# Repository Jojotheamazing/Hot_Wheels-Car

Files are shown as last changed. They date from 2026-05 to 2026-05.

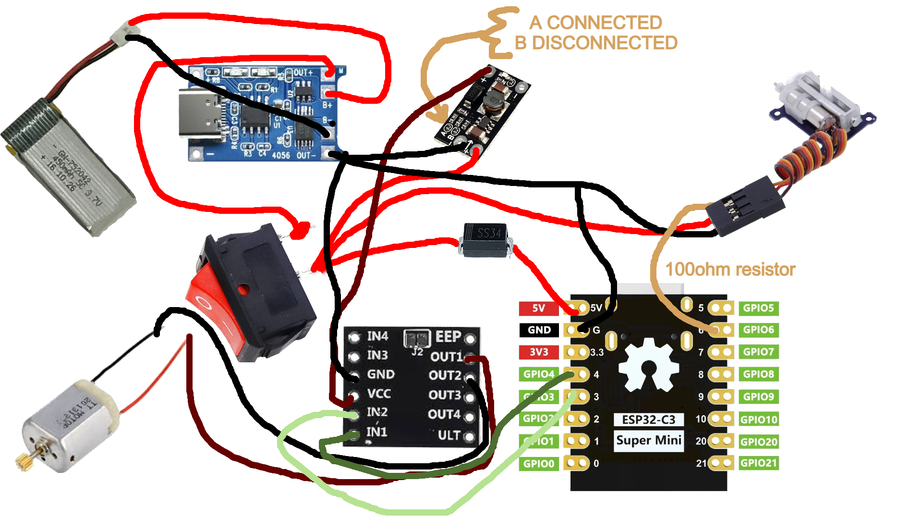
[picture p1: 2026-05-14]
Digramm.png

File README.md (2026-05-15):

# Hot_Wheels-Car

I am turning a Hot Wheels car into a fully functional RC car controlled by my phone.

So the goal is to get one of my Hot Wheels cars to be functional by adding motors, servos, and everything needed.

## The Plan

- Find the tiniest components I own since the biggest challenge will be space management.
- Design and 3D print a frame that has a steering system and holds all the components in place.
- Solder everything together and test if it goes boom or not.
- Lastly, build a website from which you can control it so there is no need to carry any controller.

## Features

- Front and backward motion through the DRV8833 motor driver.
- 45 degrees steering in each direction for better control and maybe drifting... achieved by using a 1.5 g linear servo.
- The "mind" will be an ESP32-C3 since it has Wi-Fi functions, is small, and powerful. That way control via Wi-Fi becomes possible.
- The website will be pretty basic since I can't get a specific function to work (fetch accelerometer data from phone for steering), so either 2 sliders or a joystick.
- Will include settings like:
  - Servo centre offset and limits
  - Motor limits
  - Expo throttle for smoother acceleration
  - A save button which will save the settings on the ESP32 so there isn't a need to change them every time

## Components

| Component | Purpose | Link |
|---|---|---|
| ESP32-C3 | Main controller with Wi-Fi | [AliExpress](https://www.aliexpress.com/item/1005006109082351.html) |
| DRV8833 Motor Driver | Controls the DC motor | [AliExpress]( https://www.aliexpress.com/item/1005009044264044.html) |
| 1.5 g Linear Servo | Steering system | [AliExpress](https://www.aliexpress.com/item/1005007187617708.html) |
| Coreless DC Motor | The mottion | [AliExpress](https://www.aliexpress.com/item/1005008964639480.html) |
| 601633 LiPo Battery | LiPo battery | [AliExpress](https://www.aliexpress.com/item/1005008218024646.html) |
| TP4056 Charging Module  | Battery charger | [AliExpress](https://www.aliexpress.com/item/1005005982385924.html) |
| SS12D00 3Pin Toggle Switch 1P2T 2 Position  | Power Switch | [AliExpress](https://www.aliexpress.com/item/1005005982385924.html) |
| Mini DC-DC Boost Module | Power for motor | [AliExpress](https://www.aliexpress.com/item/1005007992769446.html) |
| 1.2mm Nails | For steering wheels | Anywhere |
---
You can see and edit the 3d model in onShape: https://cad.onshape.com/documents/f10e87d5d1a2dad3236470ab/w/f1481a050fec03bc3c35e125/e/4facaef65102b49a36f9e8eb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

## Wiring

Here is an image showing all the connections but here are some notes too:
- On the boost converter you need to unsolder the b pad and only leave A soldered to set it to 9 volts
- All the Black wires are ground and it doesnt matter in which ground you connect it.
- The bright red wire is the battery power while the dark red is 9 volts so becareful not to mix it up and burn anything.
- The in1 and in2 doesnt matter if you reverse it same with out1 and out2 you might just need to reverse the diraction in the code.
  
Schematic

I should also credit an amazing YouTuber which I got inspiration for this project idea: @MaxImagination

Go check his other projects: https://www.youtube.com/@MaxImagination

Feel free to download everything and modify it however you like!

I really want to see your modifications or improvement tips, so contact me anytime!!

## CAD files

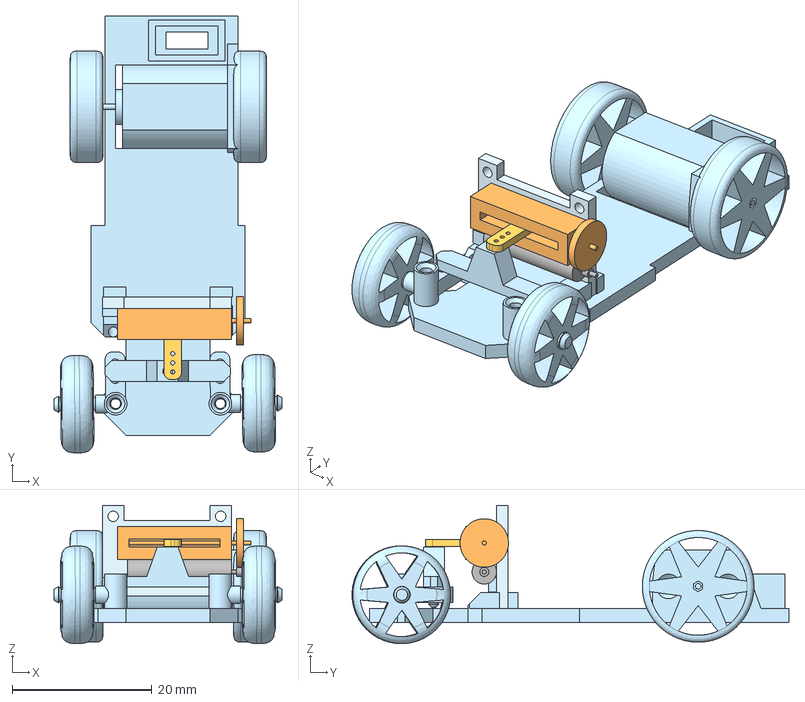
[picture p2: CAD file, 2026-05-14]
Assembly 1 Copy 1.step
32.6 x 62.6 x 19.8 mm

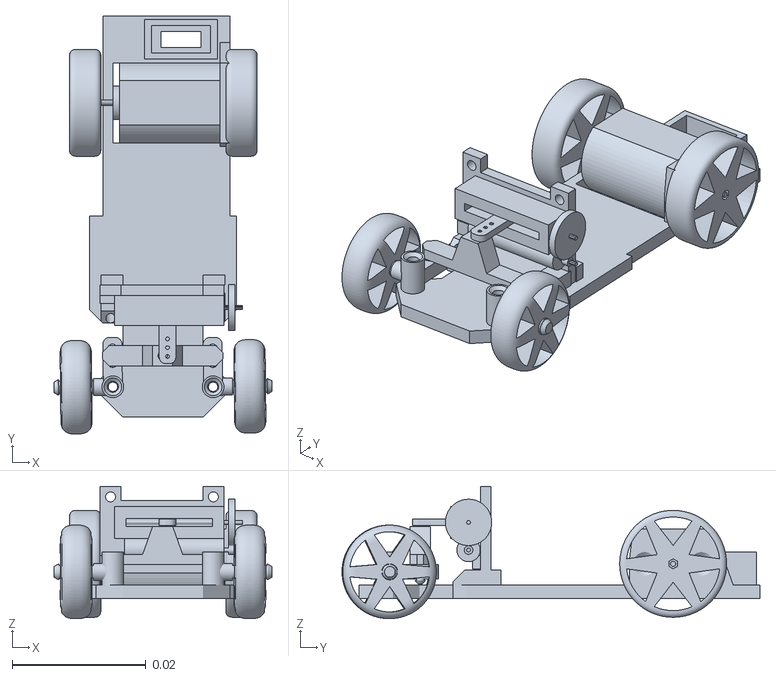
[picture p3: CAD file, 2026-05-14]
Assembly 1 Copy 1 (5).stl
0.0326 x 0.0626 x 0.0198

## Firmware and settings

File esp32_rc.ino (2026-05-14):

#include <WiFi.h>
#include <WebServer.h>
#include <WebSocketsServer.h>

// ======================
// WIFI
// ======================

const char* ssid = "ESP32_RC";
const char* password = "12345678";

// ======================
// WEB
// ======================

WebServer server(80);
WebSocketsServer ws(81);

// ======================
// PINS
// ======================

const int servoPin = 6;
const int IN1      = 3;
const int IN2      = 4;

// ======================
// SERVO (LEDC direct)
// 50Hz, 14-bit resolution
// 20000us period = 16383 ticks
// ======================

const int SERVO_FREQ = 50;
const int SERVO_BITS = 14;

const int SERVO_MIN    = 500;   // us
const int SERVO_CENTER = 1300;  // us — adjust if needed
const int SERVO_MAX    = 2100;  // us

// ======================
// MOTOR (LEDC)
// 1kHz, 8-bit resolution
// ======================

const int MOTOR_FREQ = 1000;
const int MOTOR_BITS = 8;

// ======================
// CONTROL
// ======================

int servoInput = 0;
int motorInput = 0;

unsigned long lastPacket = 0;

// ======================
// HTML
// ======================

String page = R"rawliteral(

<!DOCTYPE html>
<html>

<head>
<meta name="viewport" content="width=device-width, initial-scale=1">

<style>
body{
  font-family:Arial;
  text-align:center;
  background:#f0f0f0;
}

.box{
  background:white;
  margin:15px;
  padding:15px;
  border-radius:15px;
}

input{
  width:90%;
}
</style>

</head>

<body>

<h2>ESP32 RC</h2>

<div class="box">
<h3>Steering</h3>
<input id="servo" type="range" min="-100" max="100" value="0">
</div>

<div class="box">
<h3>Throttle</h3>
<input id="motor" type="range" min="-100" max="100" value="0">
</div>

<script>

var ws = new WebSocket("ws://192.168.4.1:81/");
var ready = false;

ws.onopen = function(){ ready = true; };
ws.onclose = function(){ ready = false; };

var servoSlider = document.getElementById("servo");
var motorSlider = document.getElementById("motor");

setInterval(function(){
  if(ready){
    ws.send("C," + servoSlider.value + "," + motorSlider.value);
  }
}, 50);

</script>

</body>
</html>

)rawliteral";

// ======================
// HTTP
// ======================

void handleRoot(){
  server.send(200, "text/html", page);
}

// ======================
// WEBSOCKET
// ======================

void onWS(
  uint8_t num,
  WStype_t type,
  uint8_t * payload,
  size_t length
){

  if(type == WStype_TEXT){

    String msg = String((char*)payload);

    if(msg.startsWith("C,")){

      sscanf(
        msg.c_str(),
        "C,%d,%d",
        &servoInput,
        &motorInput
      );

      lastPacket = millis();
    }
  }
}

// ======================
// SERVO WRITE
// us = microseconds (500-2100)
// ======================

void servoWrite(int us){
  us = constrain(us, SERVO_MIN, SERVO_MAX);
  int duty = (int)(us * 16383.0 / 20000.0);
  ledcWrite(servoPin, duty);
}

// ======================
// MOTOR WRITE
// throttle = -100 to 100
// ======================

void motorWrite(int throttle){

  if(abs(throttle) < 15){
    ledcWrite(IN1, 0);
    ledcWrite(IN2, 0);
    return;
  }

  int pwm = map(abs(throttle), 15, 100, 60, 255);
  pwm = constrain(pwm, 0, 255);

  if(throttle > 0){
    ledcWrite(IN1, pwm);
    ledcWrite(IN2, 0);
  }
  else{
    ledcWrite(IN1, 0);
    ledcWrite(IN2, pwm);
  }
}

// ======================
// SETUP
// ======================

void setup(){

  Serial.begin(115200);

  // ===== SERVO =====

  ledcAttach(servoPin, SERVO_FREQ, SERVO_BITS);
  servoWrite(SERVO_CENTER);

  delay(500);

  // ===== MOTOR =====

  ledcAttach(IN1, MOTOR_FREQ, MOTOR_BITS);
  ledcAttach(IN2, MOTOR_FREQ, MOTOR_BITS);
  ledcWrite(IN1, 0);
  ledcWrite(IN2, 0);

  // ===== WIFI =====

  WiFi.mode(WIFI_AP);
  WiFi.softAP(ssid, password);

  delay(500);

  Serial.print("AP IP: ");
  Serial.println(WiFi.softAPIP());

  // ===== SERVER =====

  server.on("/", handleRoot);
  server.begin();

  ws.begin();
  ws.onEvent(onWS);

  Serial.println("READY");
}

// ======================
// LOOP
// ======================

void loop(){

  server.handleClient();
  ws.loop();

  // ======================
  // SERVO
  // ======================

  int us = map(
    servoInput,
    -100,
    100,
    SERVO_MIN,
    SERVO_MAX
  );

  servoWrite(us);

  // ======================
  // MOTOR
  // ======================

  motorWrite(motorInput);

  // ======================
  // FAILSAFE
  // ======================

  if(millis() - lastPacket > 1000){

    servoInput = 0;
    motorInput = 0;

    servoWrite(SERVO_CENTER);

    ledcWrite(IN1, 0);
    ledcWrite(IN2, 0);
  }

  delay(2);
}
